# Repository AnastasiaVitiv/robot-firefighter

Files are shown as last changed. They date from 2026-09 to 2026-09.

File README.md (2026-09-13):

An autonomous robot built on the STM32F103 microcontroller designed for searching and automatically extinguishing fire hazards. The system detects hotspots using a thermal imaging camera, verifies target distance with a laser ToF rangefinder, and aims a pan-tilt turret equipped with a water pump.

Here is a link to a video of it.
https://drive.google.com/drive/folders/1A6Z49xJr-joiZc6H49M-nv8G-IkJ48fF?usp=sharing

Components:

Microcontroller: STM32F103C8T6.
Thermal Camera: Melexis MLX90640.
Rangefinder: VL53L1X.
Pan-Tilt Turret (2-DOF): MG995 servos driven by hardware PWM.
Extinguishing System: 5V water pump controlled via an N-channel MOSFET with flyback diode protection.
Power Supply: 2S Li-Ion battery  with step-down DC-DC converters.

Hardware Architecture & Technical Details

1. PWM Configuration
An STM32 hardware timer is used to generate 50 Hz PWM signals for servo control:
Prescaler (PSC): 35 each tick equals 1ms.
Auto-Reload Register (ARR):19999 20000ms.

2. I2C Bus Interface
Both the MLX90640 thermal camera and VL53L1X  rangefinder share the same I2C bus.
External 4.7 kOm pull-up resistors to 3.3 V ensure clean signal rise times at 400 kHz.

System Logic Flow

1.Scanning:
The STM32 reads frame data from the MLX90640 over I2C and locates the peak pixel temperature.
2.Thresholding:
If T_max > 150°C, the system calculates the angular offset of the target relative to the frame center.
3.Targeting:
Offset values update the timer's CCR registers, rotating the servo turret toward the heat source.
4. Distance Measurement & Pitch Adjustment:
The VL53L1X sensor measures the distance to the target:
   If Distance > 20 cm: The top servo tilts UP by 6° to compensate for water trajectory arc.
   If Distance > 15 cm (15–20 cm): The top servo tilts UP by 4°.
   If Distance < 15 cm: No pitch angle offset applied.
5. Suppression:The pump operates for a 5s burst, followed by a rescan to verify fire suppression.

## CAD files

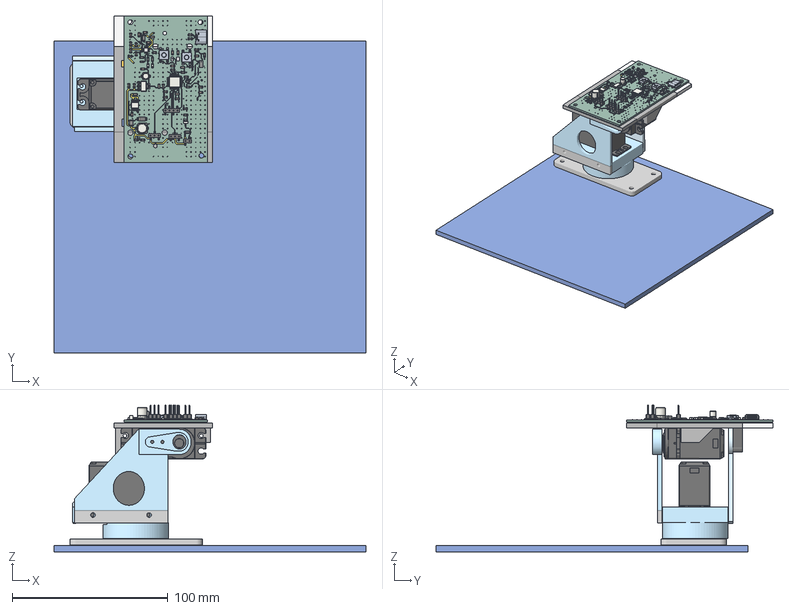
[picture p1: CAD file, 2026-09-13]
Hardware/CAD/robot fire fighter.step
200.0 x 216.0 x 94.1 mm
MG995-1 x 2
R_0805_2012Metric x 18
C_0805_2012Metric x 28
SW_SPST_Omron_B3FS-100xP x 330
SOT-223
TI_SO-PowerPAD-8
PinHeader_1x03_P254mm_Vertical_SMD_Pin1Left x 2
TSOT-23
D_SMA
R_0603_1608Metric
L_1206_3216Metric
LQFP-48_7x7mm_P0.5mm
LED_0805_2012Metric x 2
schB2F6_PCB
PinHeader_1x04_P254mm_Vertical_SMD_Pin1Left
PinHeader_1x02_P254mm_Vertical_SMD_Pin1Left
C_Elec_63x77 x 2
C_Elec_4x54 x 2
D_SOD-123
L_1210_3225Metric
VL53L0CXV0DH1 x 18
USB_C_Receptacle_GCT_USB4125-xx-x_6P_TopMnt_Horizontal x 354
schB2F6_via x 259
schB2F6_copper x 540
schB2F6_pad x 270

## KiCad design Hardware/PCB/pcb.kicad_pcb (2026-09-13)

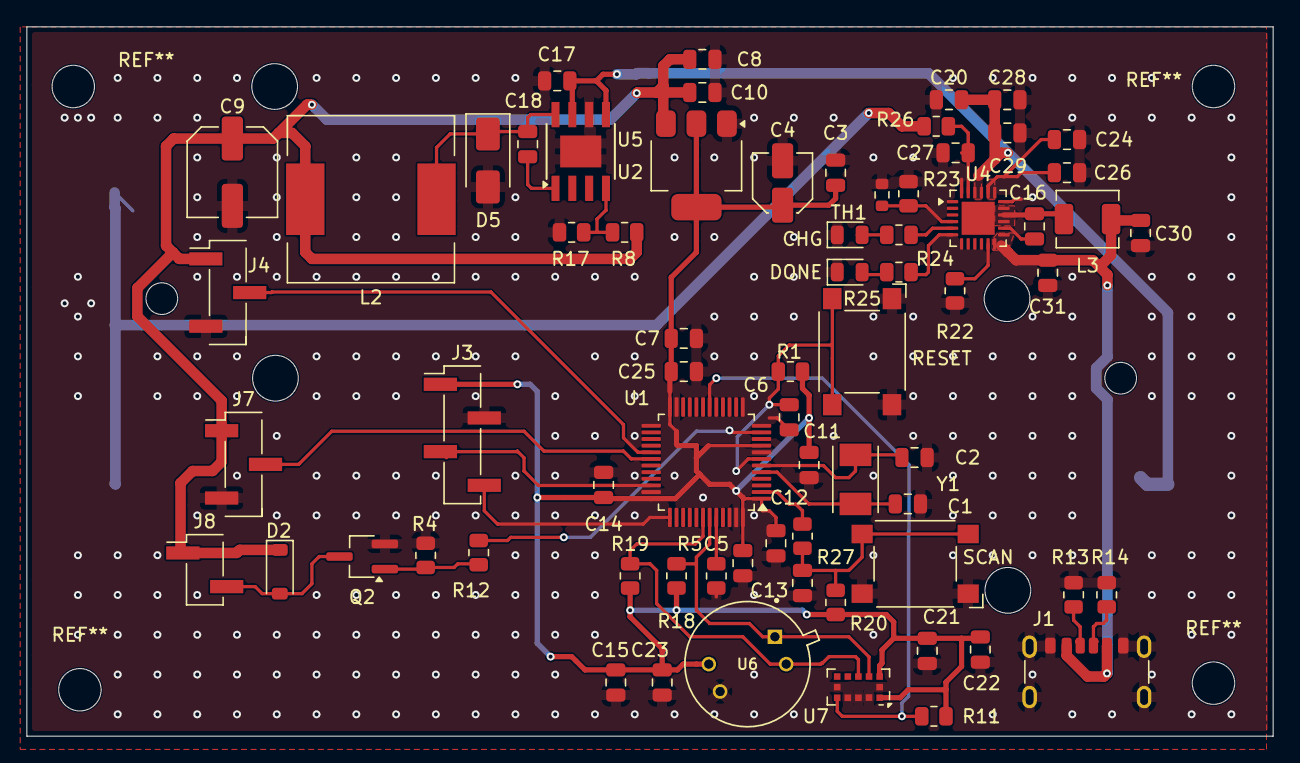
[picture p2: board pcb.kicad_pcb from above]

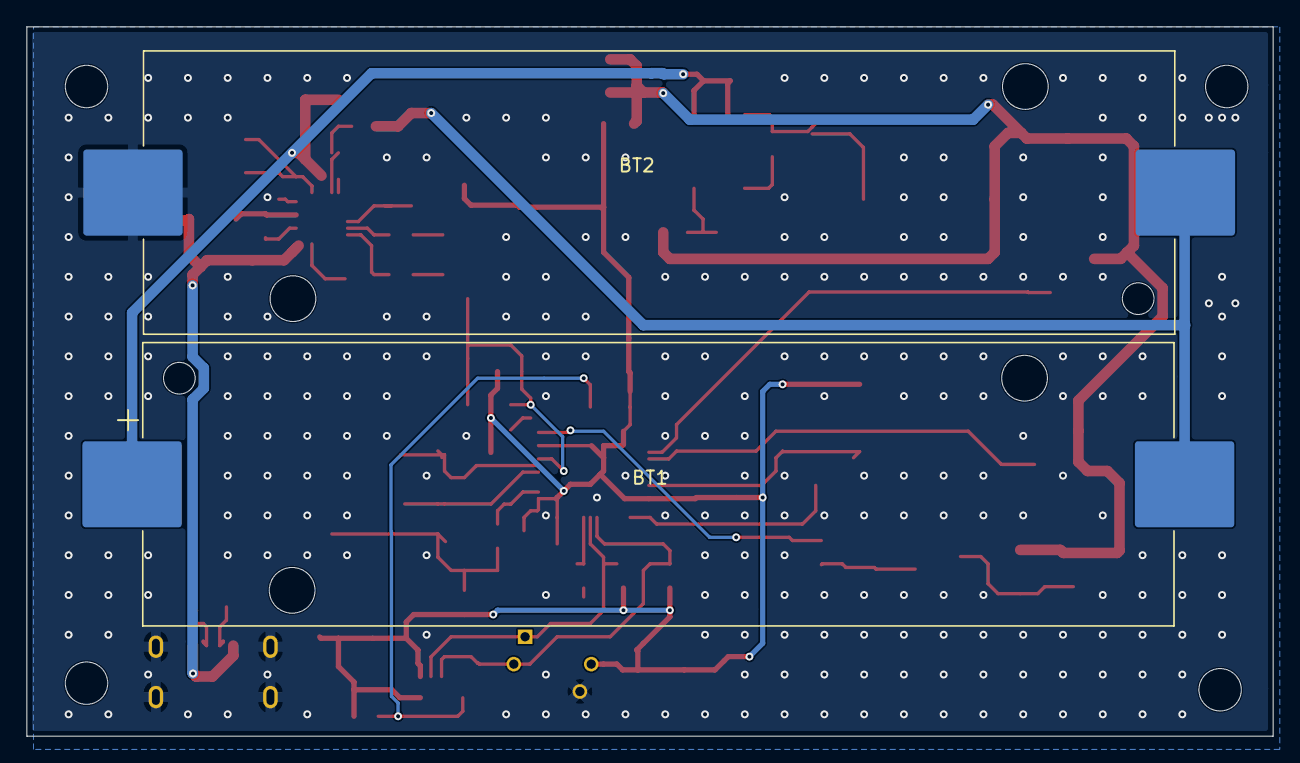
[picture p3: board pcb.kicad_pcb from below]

Board: 2 copper layers, 94.0 x 53.5 mm, 72 parts (2 on the bottom side), 37 nets.

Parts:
BT1, BT2: 18650; BatteryHolder_Keystone_1042_1x18650
C1, C2: 20pF; C_0805_2012Metric
C3, C5, C6, C7, C8, C11, C12, C13, C14, C15, C16, C20, C21, C27: 0.1uF; C_0805_2012Metric
C4: 22uF; C_Elec_4x5.4
C9: 220uF; C_Elec_6.3x7.7
C10, C17, C23, C25, C28, C29, C30, C31: 10uF; C_0805_2012Metric
C18: 0.01uF; C_0805_2012Metric
C22: 4.7uF; C_0805_2012Metric
C24, C26: 22uF; C_0805_2012Metric
CHG: LED; LED_0805_2012Metric
D2: 1N4007; D_SOD-123
D5: SS34; D_SMA
DONE: LED; LED_0805_2012Metric
J1: USB_C_Receptacle_PowerOnly_6P; USB_C_Receptacle_GCT_USB4125-xx-x_6P_TopMnt_Horizontal
J3: ST-Link; PinHeader_1x04_P2.54mm_Vertical_SMD_Pin1Left
J4: ServoX; PinHeader_1x03_P2.54mm_Vertical_SMD_Pin1Left
J7: ServoY; PinHeader_1x03_P2.54mm_Vertical_SMD_Pin1Left
J8: Pump; PinHeader_1x02_P2.54mm_Vertical_SMD_Pin1Left
L2: 22uH; L_12x12mm_H8mm
L3: 2.2uH; L_TechFuse_SL0420
Q2: AO3400A; TSOT-23_HandSoldering
R1, R5, R8, R11, R20, R26: 10kOm; R_0805_2012Metric
R4: 100kOm; R_0805_2012Metric
R12, R27: 1kOm; R_0805_2012Metric
R13, R14: 5.1kOm; R_0805_2012Metric
R17: 3.3kOm; R_0805_2012Metric
R18, R19: 4.7kOm; R_0805_2012Metric
R22: 91kOm; R_0805_2012Metric
R23: 82kOm; R_0805_2012Metric
R24, R25: 330Om; R_0805_2012Metric
RESET: SW_Push; SW_SPST_Omron_B3FS-100xP
SCAN: SW_Push; SW_SPST_Omron_B3FS-100xP
TH1: 100kOm; R_0603_1608Metric
U1: STM32F103C8Tx; LQFP-48_7x7mm_P0.5mm
U2: AMS1117-3.3; SOT-223-3_TabPin2
U4: ip2326; QFN-24-1EP_4x4mm_P0.5mm_EP2.5x2.5mmsolid thermal pad
U5: TPS5430DDA; TI_SO-PowerPAD-8
U6: MLX90640ESF-BAB-000-SP; TO292P945H1165-4
U7: VL53L0CXV0DH1; ST_VL53L0X
Y1: 8MHz; Crystal_SMD_TXC_7A-2Pin_5x3.2mm

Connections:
5V_USB: C30.1, C31.1, J1.A9 (VBUS), J1.B9 (VBUS), L3.2, U4.12, U4.13
+3.3V: C3.1, C4.1, C5.2, C7.2, C11.2, C12.2, C14.2, C15.1, C21.2, C22.2, C23.1, C25.2, J3.1, R1.1, R11.1, R18.1, R19.1, R20.1, U1.1 (VBAT), U1.9 (VDDA), U1.24 (VDD), U1.36 (VDD), U1.48 (VDD), U2.2 (VO), U6.2 (VDD), U7.1 (AVDDVCSEL), U7.11 (AVDD)
+5V: C8.1, C9.1, C10.1, D2.1 (K), J4.1, J7.1, J8.1, L2.2, R8.2, U2.3 (VI)
B+: BT1.1 (+), C17.1, C20.2, C28.1, C29.1, U4.21 (VOUT), U4.22 (VOUT), U5.5 (EN), U5.7 (VIN)
B-: BT2.2 (-), C1.1, C2.1, C3.2, C4.2, C5.1, C6.2, C7.1, C8.2, C9.2, C10.2, C11.1, C12.1, C13.1, C14.1, C15.2, C17.2, C20.1, C21.1, C22.1, C23.2, C24.2, C25.1, C26.2, C27.1, C28.2, C29.2, C30.2, C31.2, CHG.1 (K), D5.2 (A), DONE.1 (K), J1.A12 (GND), J1.B12 (GND), J1.SH (SHIELD), J3.2, J4.3, J7.3, Q2.2 (S), R4.2, R5.2, R13.2, R14.2, R17.1, R22.1, R23.1, RESET.1, SCAN.1, TH1.1, U1.8 (VSSA), U1.23 (VSS), U1.35 (VSS), U1.47 (VSS), U2.1 (GND), U4.18 (PGND), U4.24 (VBATG), U5.6 (GND), U5.9 (GNDPAD), U6.3 (GND), U7.2 (AVSSVCSEL), U7.3 (GND), U7.4 (GND), U7.6 (GND), U7.12 (GND)
BTN_SCAN: C13.2, R20.2, R27.1, SCAN.2
I2C1_SCL: R19.2, U1.42 (PB6), U6.4 (SCL), U7.9 (SDA)
I2C1_SDA: R18.2, U1.43 (PB7), U6.1 (SDA), U7.10 (SCL)
MID: BT1.2 (-), BT2.1 (+), R26.1
unnamed: C16.1, L3.1, U4.15 (LX), U4.16 (LX), U4.17 (LX)
unnamed: C24.1, C26.1, U4.19 (VSYS), U4.20 (VSYS)
unnamed: D2.2 (A), J8.2, Q2.3 (D)
unnamed: DONE.2 (A), R25.2
unnamed: C18.1, D5.1 (K), L2.1, U5.8 (PH)
unnamed: CHG.2 (A), R24.2
unnamed: J1.A5 (CC1), R13.1
unnamed: J1.B5 (CC2), R14.1
unnamed: Q2.1 (G), R4.1, R12.2
unnamed: R5.1, U1.44 (BOOT0)
unnamed: C6.1, R1.2, RESET.2, U1.7 (NRST)
unnamed: J3.3, U1.34 (PA13)
unnamed: J3.4, U1.37 (PA14)
unnamed: R27.2, U1.2 (PC13)
unnamed: C1.2, U1.5 (PD0), Y1.1
unnamed: C2.2, U1.6 (PD1), Y1.2
unnamed: R24.1, U4.5 (BAT_STAT)
unnamed: C16.2, U4.14
unnamed: R22.2, U4.11
unnamed: R25.1, U4.6
unnamed: R23.2, TH1.2, U4.4
unnamed: C27.2, R26.2, U4.23 (VBATM)
unnamed: C18.2, U5.1 (BOOT)
unnamed: R8.1, R17.2, U5.4 (VSENSE)
PUMP_GPIO: R12.1, U1.11 (PA1)
PWM_X: J4.2, U1.29 (PA8)
PWM_Y: J7.2, U1.30 (PA9)
VL53L1X_XSHUT: R11.2, U1.18 (PB0), U7.5 (XSHUT)

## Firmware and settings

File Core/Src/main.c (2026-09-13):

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
/* Includes ------------------------------------------------------------------*/
#include "main.h"
#include "i2c.h"
#include "tim.h"
#include "gpio.h"

/* USER CODE BEGIN Includes */

#include <math.h>
#include <stdint.h>

#include "MLX90640_API.h"
#include "MLX90640_I2C_Driver.h"

#include "VL53L1X_api.h"
#include "VL53L1X_calibration.h"

/* USER CODE END Includes */

/* USER CODE BEGIN PD */

#define MLX90640_ADDRESS    0x33
#define VL53L1X_ADDRESS     0x29

#define FIRE_TEMPERATURE   150.0f

#define SERVO2_MAX_ANGLE    25
#define SERVO2_MIN_ANGLE    0

#define SERVO_SCAN_STEP     10

#define PUMP_PORT   GPIOA
#define PUMP_PIN    GPIO_PIN_1

/* USER CODE END PD */


/* USER CODE BEGIN PV */
static uint16_t eeMLX90640[832];
static paramsMLX90640 mlx90640Params;
static uint16_t mlx90640Frame[834];
static float mlx90640To[768];

static uint16_t currentDistance = 0;

volatile float temperature_vdd = 0.0f;
volatile float temperature_ta = 0.0f;
volatile float temperature_tr = 0.0f;
volatile float temperature_max = 0.0f;
volatile int temperature_hottest_x = 0;
volatile int temperature_hottest_y = 0;

volatile uint8_t vl53Ready = 0;
volatile uint16_t distanceMM = 0;

volatile int mlxDumpStatus = -1;
volatile int mlxExtractStatus = -1;
volatile int mlxRefreshStatus = -1;
volatile int mlxChessStatus = -1;

volatile int vl53InitStatus = -1;
volatile int vl53StartStatus = -1;
volatile uint8_t vl53XSHUT_State;
volatile uint8_t fire_found = 0;
volatile int servo2_angle = SERVO2_MAX_ANGLE;
volatile uint8_t diagnostic_mode = 0;
volatile uint32_t last_button_press = 0;
/* USER CODE END PV */

void SystemClock_Config(void);
/* USER CODE BEGIN PFP */

static void MLX90640_UpdateTemperature(void);

static void VL53L1X_UpdateDistance(void);

static void Servo_SetAngle(uint32_t angle);
static void Servo2_SetAngle(uint32_t angle);
static void Servo2_NextStep(void);
static void Target_And_Extinguish(int *p_angle);

/* USER CODE END PFP */

/* USER CODE BEGIN 0 */
static void Servo_SetAngle(uint32_t angle)
{
    if (angle > 180)
    {
        angle = 180;
    }

    uint32_t pulse = 500 + (angle * 2000) / 180;

    __HAL_TIM_SET_COMPARE(
        &htim1,
        TIM_CHANNEL_1,
        pulse
    );
}

static void Servo2_SetAngle(uint32_t angle)
{
    if (angle > SERVO2_MAX_ANGLE)
    {
        angle = SERVO2_MAX_ANGLE;
    }

    uint32_t pulse = 500 + (angle * 2000) / 180;

    __HAL_TIM_SET_COMPARE(&htim1, TIM_CHANNEL_2, pulse);
}

static void Servo2_NextStep(void)
{
    if (servo2_angle == 25)
    {
        servo2_angle = 20;
    }
    else if (servo2_angle == 20)
    {
        servo2_angle = 10;
    }
    else if (servo2_angle == 10)
    {
        servo2_angle = 0;
    }
    else
    {
        servo2_angle = 25;
    }

    Servo2_SetAngle((uint32_t)servo2_angle);
    HAL_Delay(500);
}
static void MLX90640_UpdateTemperature(void)
{
    int frameStatus;

    float max_temp = -1000.0f;
    float sum_temp = 0.0f;

    int hottest_pixel = 0;
    int valid_pixels = 0;

    for (int subpage = 0; subpage < 2; subpage++)
    {
        frameStatus = MLX90640_GetFrameData(
            MLX90640_ADDRESS,
            mlx90640Frame
        );

        if (frameStatus < 0)
        {
            return;
        }

        temperature_vdd =
            MLX90640_GetVdd(
                mlx90640Frame,
                &mlx90640Params
            );

        temperature_ta =
            MLX90640_GetTa(
                mlx90640Frame,
                &mlx90640Params
            );

        temperature_tr =
            temperature_ta - 8.0f;

        MLX90640_CalculateTo(
            mlx90640Frame,
            &mlx90640Params,
            0.95f,
            temperature_tr,
            mlx90640To
        );
    }
    for (int i = 0; i < 768; i++)
    {
        float t = mlx90640To[i];

        if (!isfinite(t))
        {
            continue;
        }

        if (t > max_temp)
        {
            max_temp = t;
            hottest_pixel = i;
        }

        sum_temp += t;
        valid_pixels++;
    }

    if (valid_pixels == 0)
    {
        return;
    }

    temperature_max = max_temp;

    temperature_hottest_x =
        hottest_pixel % 32;

    temperature_hottest_y =
        hottest_pixel / 32;

    if (temperature_max > FIRE_TEMPERATURE)
    {
        fire_found = 1;
    }
}
static void VL53L1X_UpdateDistance(void)
{
    uint8_t dataReady = 0;

    uint16_t distance = 0;
    if (vl53InitStatus != 0)
    {
        vl53Ready = 0;

        return;
    }

    if (VL53L1X_CheckForDataReady(
            VL53L1X_ADDRESS,
            &dataReady
        ) != 0)
    {
        vl53Ready = 0;

        return;
    }

    if (dataReady)
    {
        if (VL53L1X_GetDistance(
                VL53L1X_ADDRESS,
                &distance
            ) == 0)
        {

            currentDistance = distance;

            distanceMM = distance;

            vl53Ready = 1;
            VL53L1X_ClearInterrupt(
                VL53L1X_ADDRESS
            );
        }
    }
}

/* USER CODE END 0 */

/**
  * @brief  The application entry point.
  * @retval int
  */
int main(void)
{

  /* MCU Configuration--------------------------------------------------------*/

  /* Reset of all peripherals, Initializes the Flash interface and the Systick. */
     HAL_Init();
  /* Configure the system clock */
  SystemClock_Config();

  /* Initialize all configured peripherals */
  MX_GPIO_Init();
  MX_I2C1_Init();
  MX_TIM1_Init();

  HAL_TIM_PWM_Start(&htim1, TIM_CHANNEL_1);
  HAL_TIM_PWM_Start(&htim1, TIM_CHANNEL_2);
  /* USER CODE BEGIN 2 */

  vl53Ready = 0;
    for (int attempt = 0; attempt < 5; attempt++) {
        vl53InitStatus = VL53L1X_SensorInit(VL53L1X_ADDRESS);
        if (vl53InitStatus == 0) {
            break;
        }
        HAL_Delay(20);
    }

    if (vl53InitStatus == 0)
    {
        vl53StartStatus = VL53L1X_StartRanging(VL53L1X_ADDRESS);
        if (vl53StartStatus == 0)
        {
            vl53Ready = 1;
        }
    }
      MLX90640_I2CInit();
      MLX90640_I2CGeneralReset();

      HAL_Delay(80);

      mlxRefreshStatus = MLX90640_SetRefreshRate(
          MLX90640_ADDRESS,
          0x03
      );

      if (mlxRefreshStatus != 0)
      {
          Error_Handler();
      }

      mlxChessStatus = MLX90640_SetChessMode(
          MLX90640_ADDRESS
      );

      if (mlxChessStatus != 0)
      {
          Error_Handler();
      }

      mlxDumpStatus = MLX90640_DumpEE(
          MLX90640_ADDRESS,
          eeMLX90640
      );

      if (mlxDumpStatus != 0)
      {
          Error_Handler();
      }

      mlxExtractStatus = MLX90640_ExtractParameters(
          eeMLX90640,
          &mlx90640Params
      );

      if (mlxExtractStatus != 0)
      {
          Error_Handler();
      }

      HAL_Delay(100);

      vl53Ready = 0;

      for (int attempt = 0; attempt < 5; attempt++) {
    	  vl53InitStatus = VL53L1X_SensorInit(VL53L1X_ADDRESS);
          if (vl53InitStatus == 0) {
        	  break;
          }
          HAL_Delay(20);
      }

      if (vl53InitStatus == 0)
      {
          vl53StartStatus = VL53L1X_StartRanging(
        		  VL53L1X_ADDRESS
          );

          if (vl53StartStatus == 0)
          {
        	  vl53Ready = 1;
          }
      }
  /* USER CODE END 2 */

  /* Infinite loop */
      /* USER CODE BEGIN WHILE */
      servo2_angle = 25;
      Servo2_SetAngle(25);
      while (1)
	  {
			  fire_found = 0;
			  for (int angle = 0; angle <= 80; angle += SERVO_SCAN_STEP)
			  {
				  Servo_SetAngle((uint32_t)angle);
				  HAL_Delay(500);

				  MLX90640_UpdateTemperature();
				  VL53L1X_UpdateDistance();

				  if (fire_found)
				  {
					  Target_And_Extinguish(&angle);
				  }
			  }

			  Servo2_NextStep();

			  for (int angle = 80; angle >= 0; angle -= SERVO_SCAN_STEP)
			  {
				  Servo_SetAngle((uint32_t)angle);
				  HAL_Delay(500);

				  MLX90640_UpdateTemperature();
				  VL53L1X_UpdateDistance();

				  if (fire_found)
				  {
					  Target_And_Extinguish(&angle);
				  }
			  }

              Servo2_NextStep();
	  }
     /* USER CODE END WHILE */
}

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
/* USER CODE BEGIN 4 */
void HAL_GPIO_EXTI_Callback(uint16_t GPIO_Pin)
{
    if (GPIO_Pin == GPIO_PIN_13)
    {
        uint32_t current_time = HAL_GetTick();

        if (current_time - last_button_press > 300)
        {
            diagnostic_mode = !diagnostic_mode;
            last_button_press = current_time;
        }
    }
}
/* USER CODE BEGIN 4 */

static void Target_And_Extinguish(int *p_angle)
{
    int angle = *p_angle;
    uint8_t extinguish_attempts = 0;

    Servo_SetAngle((uint32_t)angle);
    Servo2_SetAngle((uint32_t)servo2_angle);

    while (fire_found)
    {
        int sum_x = 0;
        int sum_y = 0;

        for (int i = 0; i < 2; i++)
        {
            MLX90640_UpdateTemperature();
            sum_x += temperature_hottest_x;
            sum_y += temperature_hottest_y;
            HAL_Delay(20);
        }

        int avg_x = sum_x / 2;
        int avg_y = sum_y / 2;

        if (temperature_max < FIRE_TEMPERATURE)
        {
            fire_found = 0;
            break;
        }

        uint8_t centered_x = 0;
        uint8_t centered_y = 0;

        if (avg_x < 8)
        {
            angle += 1;
            if (angle < 0) angle = 0;
        }
        else if (avg_x > 23)
        {
            angle -= 1;
            if (angle > 180) angle = 180;
        }
        else
        {
            centered_x = 1;
        }

        if (avg_y < 7)
        {
            servo2_angle -= 1;
            if (servo2_angle < 0) servo2_angle = 0;
        }
        else if (avg_y > 16)
        {
            servo2_angle += 1;
            if (servo2_angle > SERVO2_MAX_ANGLE) servo2_angle = SERVO2_MAX_ANGLE;
        }
        else
        {
            centered_y = 1;
        }

        if (centered_x == 0 || centered_y == 0)
        {

            Servo_SetAngle((uint32_t)angle);
            Servo2_SetAngle((uint32_t)servo2_angle);
            HAL_Delay(120);
        }
        else
        {
            VL53L1X_UpdateDistance();

            int offset_x = -1;
            int offset_y = 0;

            if (distanceMM <= 100)
            {
                offset_y = 0;
            }
            else if (distanceMM <= 150)
            {
                offset_y = -4;
            }
            else
            {
                offset_y = 0;
            }

            if (extinguish_attempts >= 1)
            {
                offset_y -= 2;
            }

            int camera_angle_x = angle;
            int camera_angle_y = servo2_angle;

            int target_angle = angle + offset_x;
            int target_servo2 = servo2_angle + offset_y;

            if (target_angle > 180) target_angle = 180;
            if (target_angle < 0) target_angle = 0;
            if (target_servo2 < 0) target_servo2 = 0;
            if (target_servo2 > SERVO2_MAX_ANGLE) target_servo2 = SERVO2_MAX_ANGLE;

            Servo_SetAngle((uint32_t)target_angle);
            Servo2_SetAngle((uint32_t)target_servo2);
            HAL_Delay(200);

            if (diagnostic_mode == 0)
            {
                HAL_GPIO_WritePin(PUMP_PORT, PUMP_PIN, GPIO_PIN_SET);
                for (int sweep = 0; sweep < 3; sweep++)
                {
                    Servo_SetAngle((uint32_t)(target_angle - 2));
                    HAL_Delay(400);
                    Servo_SetAngle((uint32_t)(target_angle + 2));
                    HAL_Delay(400);
                }

                HAL_GPIO_WritePin(PUMP_PORT, PUMP_PIN, GPIO_PIN_RESET);
                HAL_Delay(800);
            }
            else
            {
                HAL_Delay(2500);
            }

            extinguish_attempts++;

            angle = camera_angle_x;
            servo2_angle = camera_angle_y;
            Servo_SetAngle((uint32_t)angle);
            Servo2_SetAngle((uint32_t)servo2_angle);
            HAL_Delay(200);
        }
    }

    *p_angle = angle;
}

/* USER CODE END 4 */

/* USER CODE END 4 */
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


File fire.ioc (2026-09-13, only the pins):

Mcu.UserName=STM32F103C8Tx
PA1.Signal=GPIO_Output
PA13.Signal=SYS_JTMS-SWDIO
PA14.Signal=SYS_JTCK-SWCLK
PA8.Signal=S_TIM1_CH1
PA9.Signal=S_TIM1_CH2
PB0.Signal=GPIO_Output
PB6.Signal=I2C1_SCL
PB7.Signal=I2C1_SDA
PC13-TAMPER-RTC.Signal=GPXTI13

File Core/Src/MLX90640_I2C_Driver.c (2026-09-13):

#include "MLX90640_I2C_Driver.h"
#include "i2c.h"
#include <stdlib.h>

#define MLX90640_I2C_TIMEOUT_MS   100

#define MLX90640_MAX_WORDS        832

static I2C_HandleTypeDef *mlx_hi2c = &hi2c1;

void MLX90640_I2CInit(void)
{
}

int MLX90640_I2CGeneralReset(void)
{
    uint8_t resetCmd = 0x06;
    HAL_StatusTypeDef res = HAL_I2C_Master_Transmit(mlx_hi2c, 0x00, &resetCmd, 1,
                                                      MLX90640_I2C_TIMEOUT_MS);
    HAL_Delay(5);
    return (res == HAL_OK) ? 0 : -1;
}

int MLX90640_I2CRead(uint8_t slaveAddr,
                     uint16_t startAddress,
                     uint16_t nMemAddressRead,
                     uint16_t *data)
{
    uint8_t rxBuffer[32];

    uint16_t wordsRead = 0;

    while (wordsRead < nMemAddressRead)
    {
        uint16_t wordsToRead = nMemAddressRead - wordsRead;

        if (wordsToRead > 16)
        {
            wordsToRead = 16;
        }

        uint16_t address = startAddress + wordsRead;

        volatile uint16_t dbg_address = address;
        volatile uint16_t dbg_wordsRead = wordsRead;
        volatile uint16_t dbg_wordsToRead = wordsToRead;

        HAL_StatusTypeDef status =
            HAL_I2C_Mem_Read(
                &hi2c1,
                (slaveAddr << 1),
                address,
                I2C_MEMADD_SIZE_16BIT,
                rxBuffer,
                wordsToRead * 2,
                1000
            );

        volatile HAL_StatusTypeDef dbg_status = status;

        if (status != HAL_OK)
        {
            return -1;
        }

        volatile uint16_t dbg_block0 =
            ((uint16_t)rxBuffer[0] << 8) | rxBuffer[1];

        volatile uint16_t dbg_block1 =
            ((uint16_t)rxBuffer[2] << 8) | rxBuffer[3];

        volatile uint16_t dbg_block2 =
            ((uint16_t)rxBuffer[4] << 8) | rxBuffer[5];

        volatile uint16_t dbg_block3 =
            ((uint16_t)rxBuffer[6] << 8) | rxBuffer[7];

        for (uint16_t i = 0; i < wordsToRead; i++)
        {
            uint16_t word =
                ((uint16_t)rxBuffer[i * 2] << 8) |
                rxBuffer[i * 2 + 1];

            data[wordsRead + i] = word;
        }

        wordsRead += wordsToRead;
    }

    return 0;
}

int MLX90640_I2CWrite(uint8_t slaveAddr, uint16_t writeAddress, uint16_t data)
{
    uint8_t cmd[4];
    uint16_t check;
    HAL_StatusTypeDef res;

    cmd[0] = (uint8_t)(writeAddress >> 8);
    cmd[1] = (uint8_t)(writeAddress & 0xFF);
    cmd[2] = (uint8_t)(data >> 8);
    cmd[3] = (uint8_t)(data & 0xFF);

    res = HAL_I2C_Master_Transmit(mlx_hi2c, (uint16_t)(slaveAddr << 1), cmd, 4,
                                    MLX90640_I2C_TIMEOUT_MS);
    if (res != HAL_OK) {
        return -1;
    }

    if (MLX90640_I2CRead(slaveAddr, writeAddress, 1, &check) != 0) {
        return -1;
    }
    if (check != data) {
        return -2;
    }

    return 0;
}

void MLX90640_I2CFreqSet(int freq)
{
    (void)freq;
}

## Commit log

2026-09-13 Initial commit: Complete STM32 firefighting robot source code and docs
2026-09-13 Add hardware schematics and PCB layout
    [pcb.kicad_pcb, schematics.kicad_sch]
2026-09-13 Add 3D CAD assembly
    [pcb.kicad_pcb, robot fire fighter.step, schematics.kicad_sch]
